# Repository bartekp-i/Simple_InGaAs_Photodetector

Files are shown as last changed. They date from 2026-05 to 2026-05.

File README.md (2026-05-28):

# Simple_InGaAs_Photodetector
This repository documents how the photodetector was built, starting from developing a electronic circuit and a PCB as well as assembly and tests (ongoing)
# 6 GHz InGaAs Photodetector PCB and schematics

## Technical Specifications

| Parameter | Specification |
| :--- | :--- |
| **RF Bandwidth** | DC up to 6 GHz |
| **Characteristic Impedance** | 50 Ω (Matched Coplanar Waveguide with Ground) |
| **Bias Voltage ($V_{CC}$)** | ~12 VDC (Nominal) |
| **RF Output Interface** | Edge-Launch SMA Connector |
| **Power Supply** | 3 LiPo 3.7V Batteries via 2x4 Pin Header |
| **Design Software** | KiCad v9.0

---

## System Architecture & Circuit Design

The circuit implements a high-bandwidth, low-noise reverse-biased InGaAs photodetector topology designed to extract fast electrical transients from optical signals.

### 1. Photodiode Biasing Topology (`PD1`)
The photodiode (`PD1`) is configured in a reverse-bias configuration:
* **Cathode (Pin 1):** Connected to the filtered +12V DC bias line.
* **Anode (Pin 2):** Connected directly to the 50 Ω RF transmission line leading to the SMA output.
* **Case(Pin 3):** Directly tied to Ground to provide structural shielding.

**Why:** Applying a +12V reverse bias across the photodiode significantly widens its internal depletion region. This minimizes the junction capacitance ($C_j$), which is the primary limiting factor for high-speed photodetector bandwidth. The electrical bandwidth is governed by:

$$f_{3\text{dB}} \approx \frac{1}{2\pi \cdot R_L \cdot C_j}$$

Where $R_L$ is the 50 Ω load resistor internal to the connected measurement equipment (e.g., oscilloscope or spectrum analyzer). Minimizing $C_j$ ensures crisp pulse responses and maximum frequency extension up to 6 GHz.

### 2. Multi-Tier Power Decoupling & Low-Pass Filter Network
To prevent high-frequency RF currents from leaking into the power supply rail and to insulate the photodiode from power supply ripple, an aggressive, multi-stage cascading low-pass filter is implemented:
* **Bulk Storage (`C1`, `C2`):** A **10 µF (`C1`)** and a **6.8 µF (`C2`)** capacitor flank a **1 kΩ (`R1`)** series isolation resistor. This network forms an RC low-pass filter ($f_c \approx 23.4\text{ Hz}$) that squashes low-frequency power supply noise and ripple.
* **RF Decoupling Array (`C3`, `C4`, `C5`):** Three ultra-low Equivalent Series Resistance (ESR) and Equivalent Series Inductance (ESL) surface-mount capacitors are placed in parallel directly adjacent to the photodiode cathode: **47 pF (`C3`)**, **10 pF (`C4`)**, and **2 pF (`C5`)**. 

*Why:** Single capacitors possess self-resonant frequencies (SRF) above which they behave inductively. By staggering capacitance values down to 2 pF, the board maintains a broad, ultra-low impedance return path to ground across the entire multi-gigahertz spectrum, ensuring the photodiode sees a perfectly stable, noise-free DC bias.

---

## PCB Design & RF Considerations

At 6 GHz, electrical traces cannot be treated as simple lumped-element wires; they must be managed as **distributed-element transmission lines**. 

### 1. 50 Ω Impedance-Matched Transmission Line
The RF signal path connecting the photodiode anode to the SMA connector uses a **Coplanar Waveguide with Ground (CPWG)** geometry. 
* **Geometry:** A central signal trace surrounded on the same layer by continuous ground planes, separated by a precise air gap (0.3mm from each side), with a solid reference ground plane on the layer directly below.
* **Impedance Target:** Exactly **50 Ω** at 6 GHz. Trace width carefully designed since trace length needed to be more than λ/10 due to mechanical constraints.
* **Design Execution:** The width of the central trace and the width of the ground clearances are precisely computed based on the PCB stackup's dielectric constant ($\epsilon_r$), substrate height (FR4 or specialized high-frequency laminate), and copper thickness. This precise geometric control prevents impedance discontinuities, minimizing signal reflections and return loss ($S_{11}$).

### 2. Via Fence & Stiching
The PCB layout features a highly dense matrix of ground via stitching:
* **Via Fencing:** Rows of closely spaced via stitches flank both sides of the CPWG transmission line. This bounds the electromagnetic fields within the dielectric, suppresses parasitic substrate modes, and prevents cross-coupling or radiation loss. The distance between each via and from the edge of the trace was carefully calculated and respectively equals, 2 mm and 1.95mm (measured from centre of the via to centre of the path)
* **Resonance Suppression:** The entire board area is stitched with vias to tightly couple all ground planes together. This eliminates structural ground loops and prevents the PCB substrate from acting as a resonant cavity at microwave frequencies.
* **Mounting Hole Shielding:** All 4 mechanical mounting holes are encircled by dense via rings, binding the chassis ground firmly to the internal layer grounds to eliminate localized electromagnetic radiation.

### 3. Component Layout & RF Footprints
* **Linear Signal Flow:** The design maintains a perfectly straight. Right-angle bends are entirely avoided, as they introduce parasitic capacitive columns that degrade high-frequency signals.
* **Decoupling Proximity:** The sub-nanofarad capacitors (`C3`, `C4`, `C5`) are placed immediately adjacent to the photodiode pins using minimal trace lengths to mitigate the parasitic trace inductance that would otherwise invalidate their high-frequency filtering performance.
* **Missing Solder Mask:**  Peeling back the mask, ensures that the 6 GHz signal experiences predictable 50 $\Omega$ impedance, minimal signal attenuation, and maximum propagation speed by utilizing air as the primary upper dielectric.

---

## Component Bill of Materials (BOM)

| Reference | Qty | Value | Package | Description |
| :--- | :--- | :--- | :--- | :--- |
| **PD1** | 1 | InGaAs Photodiode | 3-Pin Package | High-bandwidth Photodiode (6 GHz) |
| **J1** | 1 | CON-SMA-EDGE-SRP | Edge-Mount SMA | 50 Ω Female RF Edge-Launch Connector |
| **J2** | 1 | 2x4 Header (2.54mm) | Thru-Hole | Power/GND Distribution Interface |
| **R1** | 1 | 1 kΩ | SMD 0402/0201 | Thick/Thin Film Isolation Resistor |
| **C1** | 1 | 10 µF | SMD 0805/1206 | Ceramic Bulk Capacitor |
| **C2** | 1 | 6.8 µF | SMD 0805 | Ceramic Bulk Filter Capacitor |
| **C3** | 1 | 47 pF | SMD 0402/0201 | Ultra-Low ESR High-Q RF Capacitor |
| **C4** | 1 | 10 pF | SMD 0402/0201 | Ultra-Low ESR High-Q RF Capacitor |
| **C5** | 1 | 2 pF | SMD 0402/0201 | Ultra-Low ESR High-Q RF Capacitor |

## PCB and Schematic



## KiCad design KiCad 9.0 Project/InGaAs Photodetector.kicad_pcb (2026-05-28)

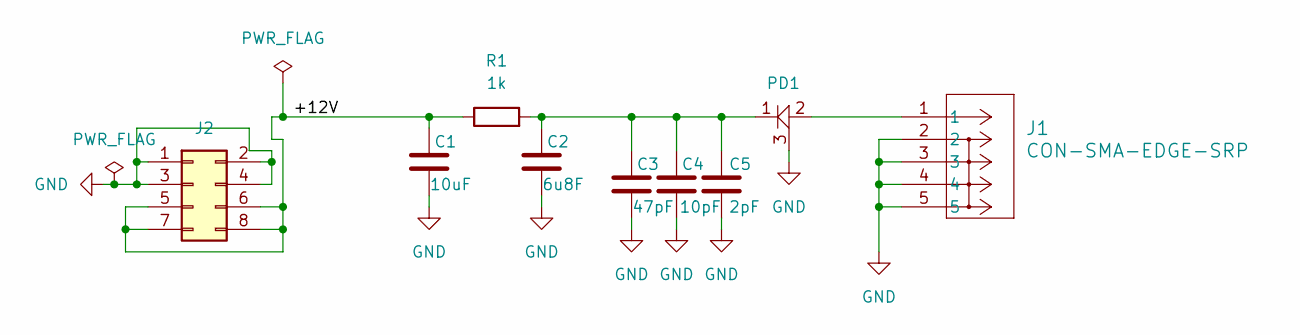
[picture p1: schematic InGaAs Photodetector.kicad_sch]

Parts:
C1: 10uF; C_0805_2012Metric
C2: 6u8F; C_0805_2012Metric
C3: 47pF; C_0402_1005Metric
C4: 2pF; C_0402_1005Metric
C5: 10pF; C_0402_1005Metric
J1: CON-SMA-EDGE-SRP; Untitled
J2: Conn_02x04_Odd_Even; heder2x4
PD1: Photodiode
R1: 1k; R_0402_1005Metric

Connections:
/+12V: C1.1, J2.5, J2.6, J2.7, J2.8, R1.1
GND: C1.2, C2.2, C3.2, C4.2, C5.2, J1.2, J1.3, J1.4, J1.5, J2.1, J2.2, J2.3, J2.4, PD1.3 (Case)
unnamed: J1.1, PD1.2 (Anode)
unnamed: C2.1, C3.1, C4.1, C5.1, PD1.1 (Cathode), R1.2

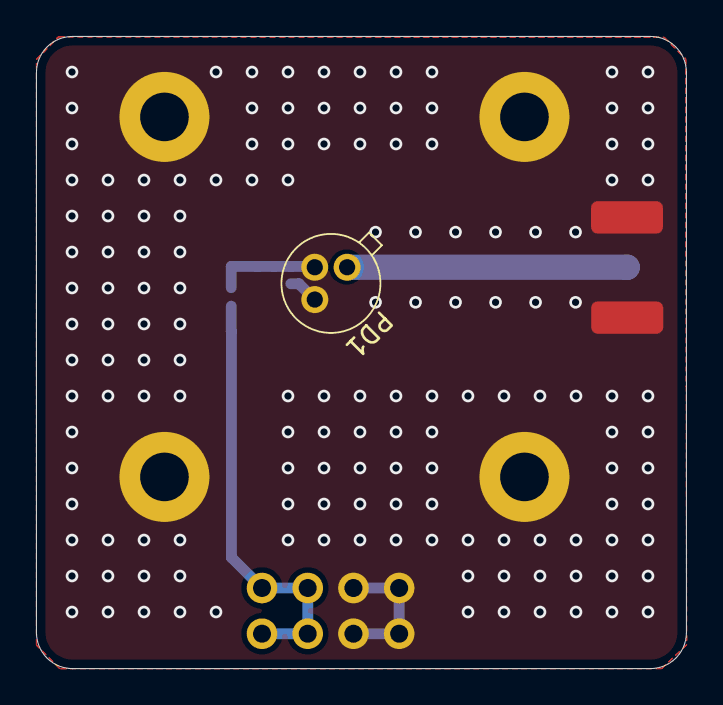
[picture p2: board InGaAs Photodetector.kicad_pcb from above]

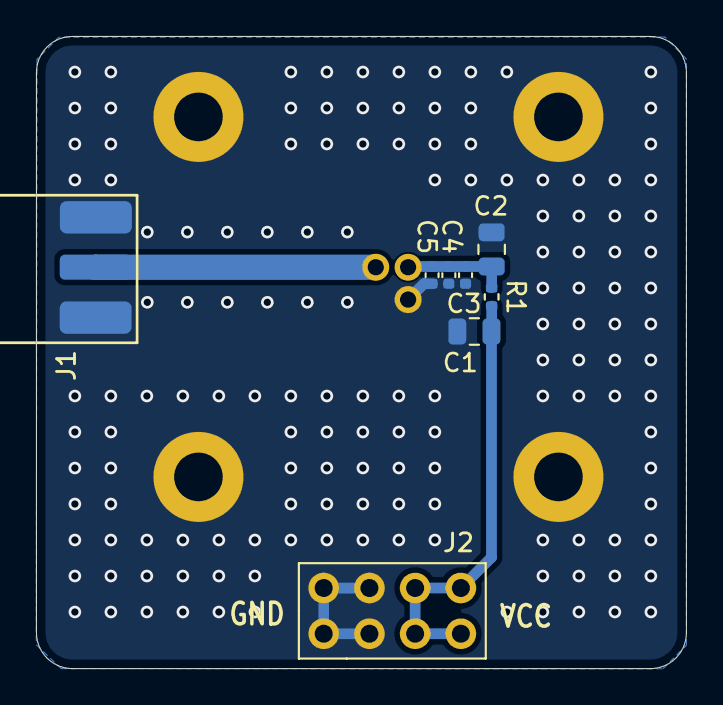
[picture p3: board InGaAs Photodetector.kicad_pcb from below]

Board: 2 copper layers, 36.1 x 35.1 mm, 9 parts (8 on the bottom side), 4 nets.
